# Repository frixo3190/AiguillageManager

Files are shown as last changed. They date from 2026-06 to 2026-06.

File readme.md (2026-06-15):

# 🚂 AiguillageManager — Pilotez en DCC vos aiguillages à solénoïde

<p align="center">
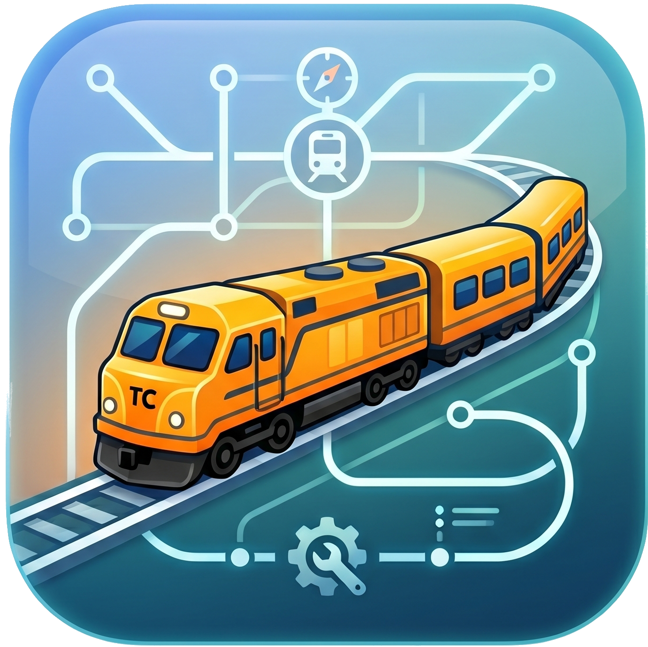
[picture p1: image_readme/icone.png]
AiguillageManager
  
</p>

Le but de ce projet est de numériser et de rendre compatibles DCC les aiguillages à bobines traditionnels (les modèles analogiques classiques que l'on trouve d'occasion pour quelques euros).

<p align="center">
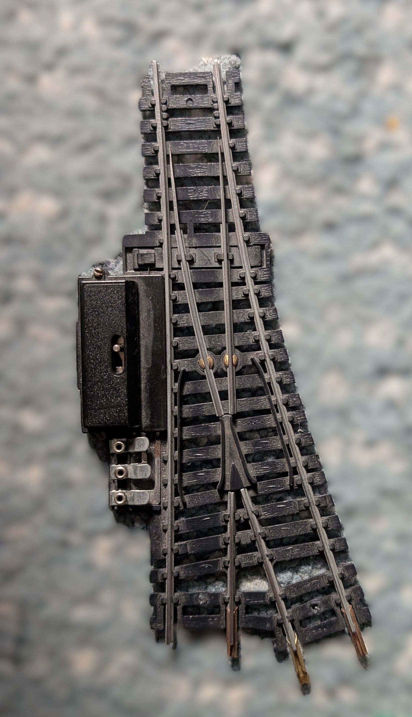
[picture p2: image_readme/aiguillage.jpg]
Aiguillage à bobine traditionnel
  
  <br><em>Aiguillage à bobine standard — le genre d'aiguillage que ce projet permet de piloter en Wi-Fi et en DCC.</em>
</p>

Grâce à ce boîtier, vous pouvez piloter vos aiguillages de deux manières :

- **En Wi-Fi :** Via une ou plusieurs tablettes tactiles synchronisées en temps réel, qui affichent le tracé de votre réseau avec des boutons interactifs.
- **En DCC :** Directement depuis votre télécommande MultiMAUS branchée sur votre centrale ferroviaire.

---

## ✨ Fonctionnalités

### Interface Web (TCO tactile)
- Design glassmorphism, fond de plan personnalisable
- Mode Utilisateur / Mode Configuration
- Drag & drop des switchs, masquage, redimensionnement
- Zoom ×2 à ×10, zoom libre
- Panneau **Historique** des actions
- Panneau **DCC log** : toutes les commandes DCC reçues, avec filtre "aiguillages uniquement"
- **Gyrophare rouge** et sirène 3s quand le signal DCC est perdu
- Badge DCC OK / KO / Arrêt Urgence 🚨
- Bouton **Muette** 🔊/🔇 l'alerte sonore
- Clic sur "DCC OK" → historique DCC ; clic sur 📜 → historique actions

### DCC
- Détection et décodage des adresses d'aiguillage (formule universelle `((addr-33016)/256)*4 + ((addr-33016)%256)/2 + 1`)
- Mapping configurable : chaque switch peut répondre à n'importe quelle adresse DCC (1-99)
- Ordres d'ouverture / fermeture avec sons distincts (notes ascendantes/descendantes)
- Arrêt d'urgence (overlay rouge + badge clignotant + son)
- `logdcc(true/false)` — log brut en console
- `logPin(true/false)` — monitoring de la pin DCC

### WiFi
- Connexion non-bloquante (le serveur démarre sans attendre le WiFi)
- Reconnexion automatique
- LED interne clignote si WiFi perdu
- OTA (mise à jour firmware et filesystem par WiFi)
- Heartbeat toutes les 5s avec timeout 15s (détection de perte de connexion)

### Console navigateur
| Commande | Description |
|---|---|
| `help()` | Affiche l'aide |
| `logdcc(true/false)` | Log DCC brut dans la console |
| `logPin(true/false)` | Active la surveillance pin DCC |
| `cancel_detect_dcc_off(true/false)` | Ignore la perte de signal DCC |

---

## 🛠️ Hardware

Pour matérialiser ce projet, il est nécessaire de fabriquer une carte électronique sur mesure qui sert d'interface de puissance et de sécurité. Vous trouverez dans ce projet un dossier nommé `gerber.zip` contenant tous les fichiers de fabrication industriels.

Pour la commande du PCB, vous pouvez passer par **JLCPCB** (aucun lien ni affiliation). En dehors du délai de livraison proche d'un mois, c'est vraiment le moins cher. Il vous suffit de téléverser le fichier `gerber.zip` sur leur site pour commander et faire imprimer le circuit imprimé professionnel pour moins de 10 €.

Pour les pièces détachées (composants électroniques), je conseille **AliExpress** (aucun lien ni affiliation).

Une fois la carte et les composants reçus, il faudra souder le tout vous-même.

<p align="center">
  Circuit imprimé (PCB)
  <br><em>Carte électronique du projet — interface de puissance et de sécurité pour 6 aiguillages.</em>
</p>

<p align="center">
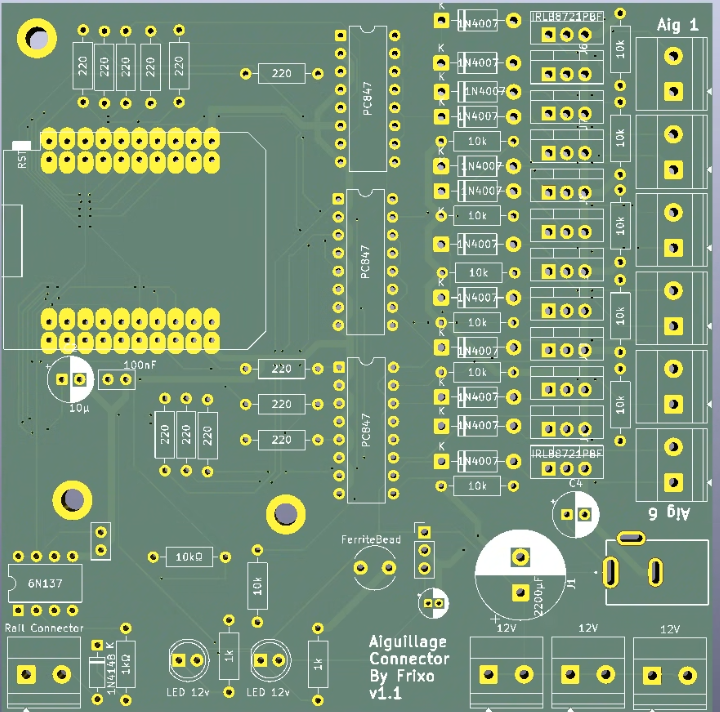
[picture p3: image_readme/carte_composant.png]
PCB avec références des composants
  
  <br><em>PCB avec l'emplacement et les références de chaque composant.</em>
</p>

<p align="center">
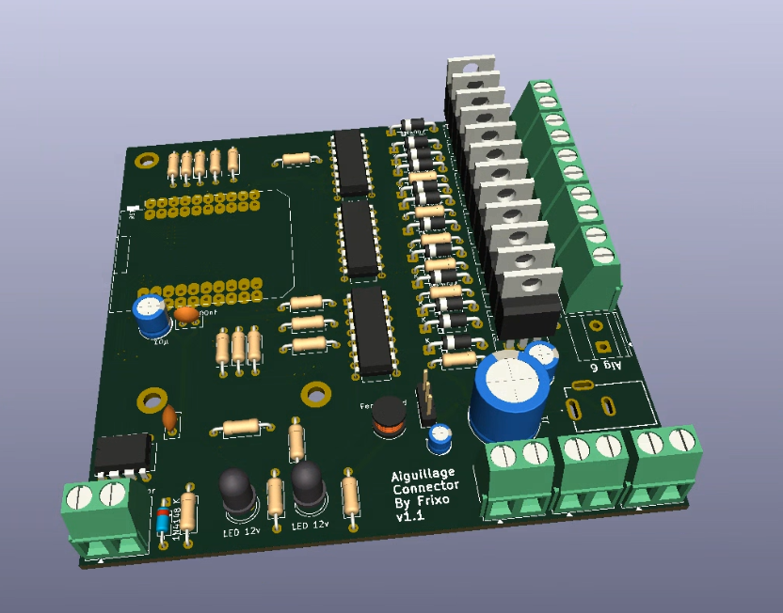
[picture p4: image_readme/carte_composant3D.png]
PCB avec composants 3D
  
  <br><em>PCB avec les composants 3D — vue réaliste de la carte une fois assemblée.</em>
</p>

<p align="center">
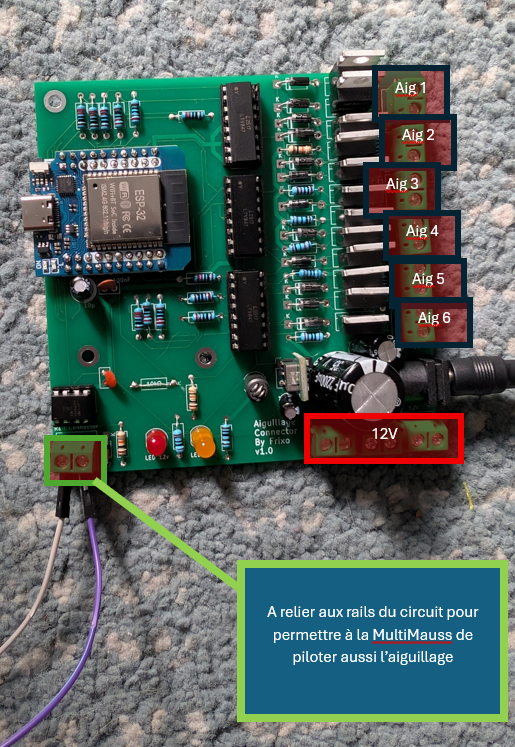
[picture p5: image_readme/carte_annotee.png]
Carte et aiguillage annotés
  
  <br><em>Carte et aiguillage annotés — repérage des principaux composants et connexions.</em>
  <br><em>⚠️ Sur la photo, on voit qu'une résistance de 10 kΩ a été shuntée. Il s'agit d'une erreur de conception de la V1.0, corrigée dans la <strong>V1.1</strong> (présente dans ce projet). Dans la V1.1, cette résistance est correctement soudée sur le circuit imprimé. Dans la V1.0, la résistance est également présente mais a dû être soudée manuellement à l'arrière de la carte de façon peu propre.</em>
</p>

<p align="center">
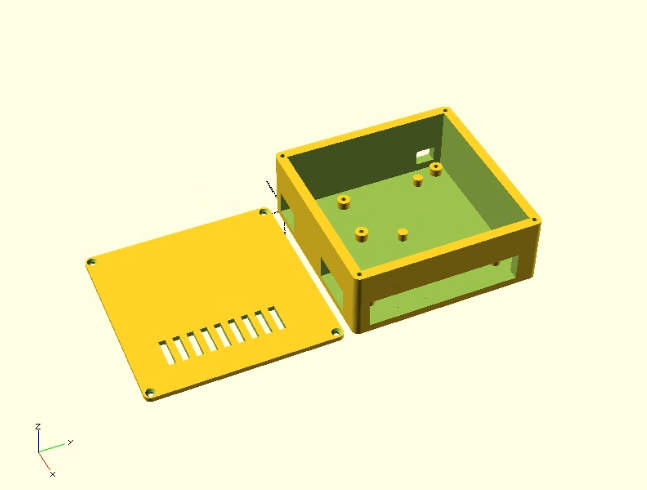
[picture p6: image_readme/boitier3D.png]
Boîtier 3D
  
  <br><em>Boîtier d'impression 3D — pour protéger la carte électronique et la connectique.</em>
</p>

Un fichier **STL** est inclus dans ce projet pour imprimer un boîtier de protection adapté aux dimensions exactes du PCB. Il est recommandé d'imprimer ce boîtier en **PETG** (éviter l'ABS, car la carte peut chauffer un peu). Le fichier STL doit être transformé en GCode comme d'habitude — je conseille le logiciel **CURA** (aucun lien ni affiliation).

En entrée, cette carte doit être alimentée par un **bloc d'alimentation 12V - 2A** (référence exacte : alimentation à découpage 12V 2A avec connecteur Jack DC 5.5 × 2.1 mm). Une fois cette alimentation branchée sur le connecteur Jack de la carte, il n'est plus du tout nécessaire d'alimenter l'ESP32 en USB-C, car le circuit s'occupe de réguler et de distribuer l'énergie nécessaire au microcontrôleur.

En sortie, cette carte électronique fournit de quoi alimenter **jusqu'à 6 aiguillages standards en 12V**, et permet de contrôler individuellement le basculement dans les deux sens (voie directe ou voie déviée) pour chacun de ces 6 aiguillages.

Pour cela, le circuit intègre une **triple sécurité** indispensable :
- L'**optocoupleur rapide 6N137** isole et protège l'ESP32 des tensions élevées et des parasites de la voie DCC.
- Des **optocoupleurs PC817** isolent totalement la partie commande basse tension (3,3V) de la partie puissance (12V) des aiguillages.
- Des **transistors MOSFET** font office d'interrupteurs "gros bras" pour encaisser et envoyer le fort ampérage (plusieurs Ampères) réclamé par les bobines analogiques sans surcharger le microcontrôleur.

### Liste des composants

| Composant | Description / Rôle | Qté |
|---|---|---|
| Module WiFi D1 MINI ESP32 | Microcontrôleur (cerveau du projet, version 30 ou 38 broches selon votre PCB) | 1 |
| Optocoupleur 6N137 | Isolation haute vitesse pour la lecture du signal DCC des rails | 1 |
| Support DIP-8 | Support pour accueillir l'optocoupleur 6N137 sans avoir à le souder directement | 1 |
| Optocoupleurs PC817 | Isolation des signaux de commande des aiguillages (sécurité CPU) | 12 |
| Supports DIP-4 | Supports pour accueillir les 12 optocoupleurs PC817 | 12 |
| Transistors MOSFET | Interrupteurs de puissance pour envoyer les Ampères aux bobines | 12 |
| Diodes 1N4148 | Diode de commutation rapide pour le circuit d'entrée DCC | 1 |
| Diodes 1N4007 | Diodes de roue libre pour protéger le circuit des retours de force des bobines | 12 |
| Résistance 1 kΩ | Protection de la LED interne de l'optocoupleur 6N137 | 1 |
| Résistance 10 kΩ | Résistance de Pull-Up pour la ligne de signal DCC (broche 6) | 1 |
| Résistances (220 Ω à 1 kΩ) | Résistances de commande pour les lignes des transistors | 12 |
| Condensateur 100 nF | Condensateur de découplage pour stabiliser l'alimentation du 6N137 | 1 |
| Borniers à vis 5.08 mm | Connecteurs pour l'arrivée des rails et les sorties vers les aiguillages | Selon design |
| Inducteur de perle de ferrite (6 canaux) | Filtre antiparasite multi-lignes pour bloquer les bruits électromagnétiques | 1 |
| Prise Jack DC femelle | Connecteur d'alimentation pour recevoir le bloc 12V (5.5 × 2.1 mm) | 1 |

> ⚠️ **Conseil important :** Prenez le temps de bien souder chaque composant, dans le bon sens. Un défaut de soudure (point sec, court-circuit, composant inversé) peut rendre la carte inopérante, voire endommager définitivement l'ESP32 ou les composants connectés. Une inspection visuelle à la lampe et un passage au multimètre avant la mise sous tension sont vivement recommandés.

### Détails de conception

- ESP32 Wemos D1 mini32
- Optocoupleur 6N137 pour isolation DCC
- 12 MOSFETs pour piloter 6 aiguillages double-bobine
- Protection anti-surchauffe (impulsions 500ms)
- Synchronisation physique au démarrage (impulsions espacées 600ms)

---

## 🔐 Fichier `secrets.h` (obligatoire)

Avant de compiler, crée le fichier `src/secrets.h` avec tes identifiants WiFi :

```cpp
#ifndef SECRETS_H
#define SECRETS_H

#define WIFI_SSID "ton_ssid"
#define WIFI_PASSWORD "ton_mot_de_passe"

#endif
```

Ce fichier est dans `.gitignore` → pas de risque de l'uploader sur GitHub.

---

## 📦 Upload & Flash

### Première fois (filaire USB)
```bash
pio run -t upload           # Flash firmware
pio run --target uploadfs   # Upload filesystem (HTML/CSS/JS/images)
```

### OTA (mise à jour WiFi)
```bash
pio run -t upload --upload-port AiguillageManager.local
pio run --target uploadfs --upload-port AiguillageManager.local
```

---

## 🔧 Configuration

### Attribution d'adresse DCC
1. Passer en **Mode Configuration**
2. Cliquer droit sur un switch → "Attribuer une adresse d'aiguillage"
3. Saisir un numéro (1-99)
4. Le numéro s'affiche sur le switch

### Plan de fond
1. Mode Configuration → "Plan" → Upload/Photo
2. L'image est redimensionnée à 1920px max et stockée sur l'ESP

---

## 🔄 Historique des versions

- **v1.15+** : Mapping DCC configurable, panneau DCC log, gyrophare, sirène, OTA, heartbeat, badges DCC OK/KO/Urgence

---

## ⚖️ Avertissement légal

Ce projet est fourni à titre éducatif et récréatif. La fabrication, le câblage, la mise sous tension et l'utilisation de cette carte électronique se font **sous votre entière responsabilité**.

Le créateur de ce projet ne peut être tenu responsable :
- d'un défaut de fabrication,
- d'une erreur de conception,
- d'un mauvais branchement,
- d'un court-circuit,
- d'un incendie ou de tout autre dommage matériel ou corporel,
- ni de toute conséquence directe ou indirecte liée à l'utilisation de ce projet.

En réalisant ce projet, vous reconnaissez avoir les compétences nécessaires en soudure et en électronique, ou accepter de vous former avant de commencer.

---

## 🧩 Licence & Crédits

Ce projet est **entièrement libre et open-source**. Vous pouvez l'utiliser, le modifier, le partager et le distribuer sans aucune restriction.

Seule petite attention : si vous le partagez, présentez-le ou en parlez autour de vous, merci de mentionner qu'il a été créé **by Frixo**.

Développé sous supervision humaine, code généré par IA.
Librairies : NmraDcc, ESPAsyncWebServer, ArduinoJson.

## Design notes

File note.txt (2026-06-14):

lancer l'upload littlefs pour les maj web :
pio run --target uploadfs

pio run -t upload --upload-port 192.168.70.43

pio run --target uploadfs --upload-port 192.168.70.43

pio run --target uploadfs --upload-port AiguillageManager.local

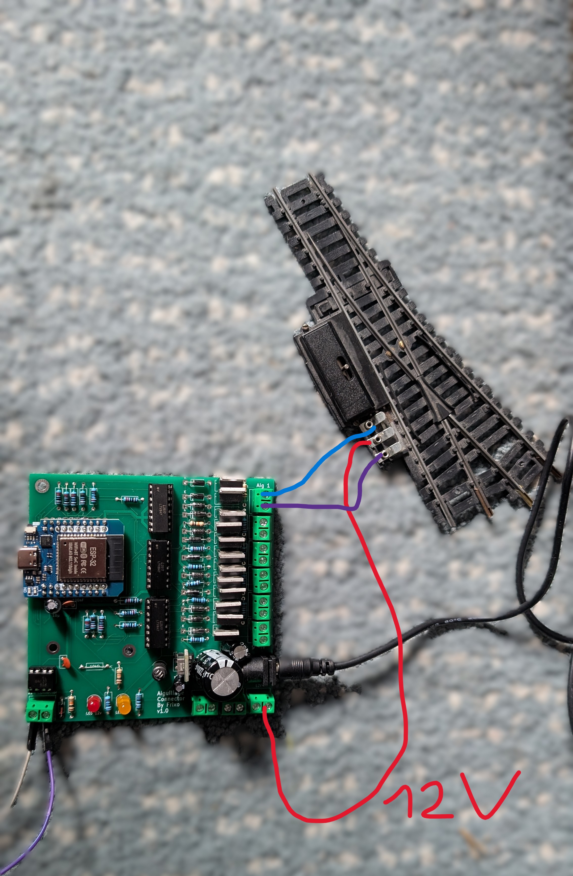
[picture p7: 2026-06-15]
image_readme/non utilisé/carte et aiguillage.jpg

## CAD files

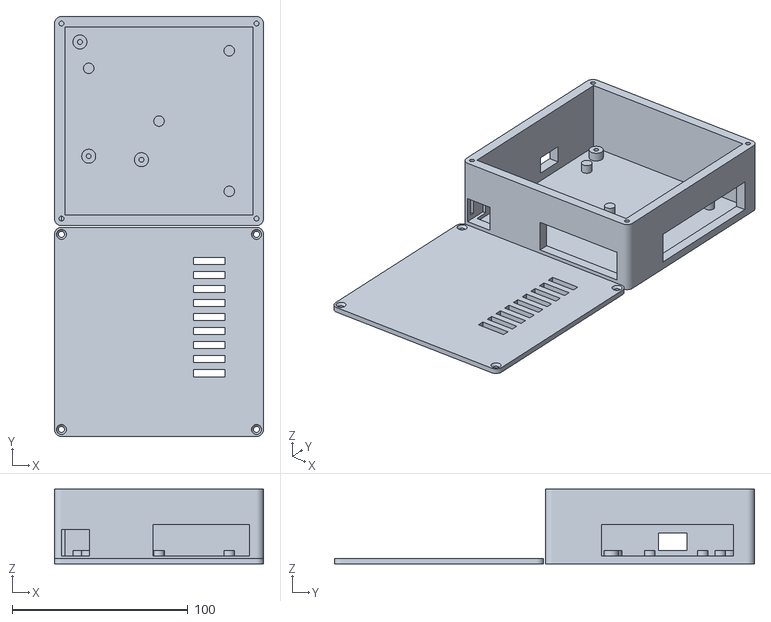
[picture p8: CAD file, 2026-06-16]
boite.stl
119.0 x 239.0 x 42.5

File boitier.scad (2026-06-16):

// --- CONFIGURATION ---
pcb_x = 100; 
pcb_y = 100; 
h_int = 40; 
ep = 2.5; 
marge = 3.5; // Offre 2mm de jeu de chaque côté à l'intérieur
$fn = 64; 

// Positions des 3 trous de vis PCB
trous_pcb = [[5, 95], [10, 30], [40, 28]]; 

// Positions des supports anti-torsion
supports_appui = [[10, 80], [90, 10], [90, 90], [50, 50]];

module base_boitier() {
    difference() {
        // 1. CORPS EXTERNE
        hull() {
            for(x=[0, pcb_x+11], y=[0, pcb_y+11]) 
                translate([x,y,0]) cylinder(h=h_int+ep, r=4);
        }
        
        // 2. VIDAGE INTERNE (Avec le jeu de 2mm de chaque côté)
        translate([2, 2, ep])
            cube([pcb_x+7, pcb_y+7, h_int + 5]);

        // 3. OUVERTURE USB-C (Flanc gauche)
        translate([-5, 60.5, ep+5]) cube([15, 16, 10]); 
        
        // 4. OUVERTURE BORNIERS DROITE (Aiguillages 1 à 6)
        translate([pcb_x+6, 28, ep+2]) cube([10, 75, 18]);
        
        // 5. OUVERTURES BAS
        // Ouverture J2 (DCC Rail) en bas à gauche
        translate([0, -5, ep+2]) cube([16, 15, 15]);
        
        // AJUSTEMENT ICI : Découpe resserrée sur le coin inférieur droit
        // Démarre à X=52 (au lieu de 46) pour éviter le grand vide à gauche du bornier J5
        translate([52, -5, ep+2]) cube([55, 35, 18]);

        // 6. TROUS POUR VIS DU COUVERCLE
        for(x=[0, pcb_x+11], y=[0, pcb_y+11]) {
            translate([x, y, ep + 5]) cylinder(h=h_int, r=1.4);
        }
    }

    // PLOTS DE FIXATION PCB (Centrés)
    for (t = trous_pcb) {
        translate([t[0]+5.5, t[1]+5.5, ep])
            difference() {
                cylinder(h=5, r=4);
                translate([0,0,-1]) cylinder(h=7, r=1.4); 
            }
    }

    // SUPPORTS ANTI-TORSION
    for (s = supports_appui) {
        translate([s[0]+5.5, s[1]+5.5, ep]) cylinder(h=5, r=3);
    }
}

module couvercle() {
    translate([0, -120, 0]) 
    difference() {
        // Plaque du couvercle
        hull() {
            for(x=[0, pcb_x+11], y=[0, pcb_y+11]) 
                translate([x,y,0]) cylinder(h=3, r=4);
        }
        
        // TROUS DE PASSAGE VIS M3 (fraisés)
        for(x=[0, pcb_x+11], y=[0, pcb_y+11]) {
            translate([x,y,-1]) cylinder(h=5, r=1.7); 
            translate([x,y,1.5]) cylinder(h=2, r1=1.7, r2=3.2); 
        }
            
        // FENTES D'AÉRATION (Zone MOSFETs)
        for(i=[0:8]) translate([75, 30 + i*8, -1]) cube([18, 4, 5]);
    }
}

// Appel des modules
base_boitier();
couvercle();

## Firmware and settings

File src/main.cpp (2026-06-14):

#include <Arduino.h>
#include <WiFi.h>
#include <ESPAsyncWebServer.h>
#include <LittleFS.h>
#include <ArduinoJson.h>
#include <ESPmDNS.h>
#include <NmraDcc.h>
#include <ArduinoOTA.h>
#include "secrets.h"

const char* ssid = WIFI_SSID;
const char* password = WIFI_PASSWORD;

AsyncWebServer server(80);

NmraDcc Dcc;

#define DCC_PIN 16
#define DCC_SIGNAL_TIMEOUT 500

unsigned long pinTimers[40] = {0};
int switchStates[6] = {0};
int switchDccAddresses[6] = {1, 2, 3, 4, 5, 6};
AsyncEventSource * events;
unsigned long lastDccSignal = 0;
bool signalPresent = true;
int dccPinLastState = -1;
unsigned long lastDccPinEvent = 0;
bool dccPinLogEnabled = false;
bool emergencyStopActive = false;
unsigned long emergencyStartTime = 0;
uint16_t lastUnknownAddr = 0;
uint8_t lastUnknownCmd = 0;
unsigned long lastUnknownTime = 0;

const int pinsAiguillages[6][2] = {
  {26, 17}, 
  {18, 19}, 
  {21, 22}, 
  {23, 25}, 
  {27, 32}, 
  {33, 14}  
};

void loadDccAddresses() {
  File configFile = LittleFS.open("/config.json", "r");
  if (configFile) {
    StaticJsonDocument<2048> doc;
    DeserializationError error = deserializeJson(doc, configFile);
    if (!error) {
      JsonArray switches = doc["switches"];
      int i = 0;
      for (JsonObject sw : switches) {
        if (i >= 6) break;
        switchDccAddresses[i] = sw["dccAddress"] | (i + 1);
        i++;
      }
      for (; i < 6; i++) {
        switchDccAddresses[i] = i + 1;
      }
    }
    configFile.close();
  }
}

void notifyDccMsg(DCC_MSG * msg) {
  lastDccSignal = millis();
  if (emergencyStopActive && emergencyStartTime > 0 && (millis() - emergencyStartTime > 2000)) {
    emergencyStopActive = false;
  }
  if (!signalPresent) {
    signalPresent = true;
    events->send("{\"present\":true}", "dcc-signal");
  }
  
  if (msg->Size >= 3) {
    uint16_t addr = (msg->Data[0] << 8) | msg->Data[1];
    uint8_t cmd = msg->Data[2];
    
    int base = addr - 33016;
    int calcSwitch = (base / 256) * 4 + ((base % 256) / 2) + 1;
    int mode = (addr % 2) + 1;
    
    int switchId = -1;
    for (int i = 0; i < 6; i++) {
      if (switchDccAddresses[i] == calcSwitch) {
        switchId = i;
        break;
      }
    }
    if (switchId < 0 && calcSwitch >= 1 && calcSwitch <= 6) {
      switchId = calcSwitch - 1;
    }
    
    if (switchId >= 0) {
      int pinIndex = mode - 1;
      int pinToPulse = pinsAiguillages[switchId][pinIndex];
      
      Serial.println("DCC: Aiguillage " + String(calcSwitch) + " mode " + String(mode));
      
      switchStates[switchId] = mode - 1;
      
      digitalWrite(pinToPulse, HIGH);
      pinTimers[pinToPulse] = millis();
      if (pinTimers[pinToPulse] == 0) pinTimers[pinToPulse] = 1;
      
      char jsonBuf[200];
      snprintf(jsonBuf, sizeof(jsonBuf), "{\"id\":%d,\"state\":%d,\"source\":\"dcc\",\"address\":%d,\"cmd\":%d}", switchId, switchStates[switchId], addr, cmd);
      events->send(jsonBuf, "dcc-switch");
    } else {
      if (addr == lastUnknownAddr && cmd == lastUnknownCmd && millis() - lastUnknownTime < 1000) {
        // already reported, skip
      } else {
        lastUnknownAddr = addr;
        lastUnknownCmd = cmd;
        lastUnknownTime = millis();
        Serial.printf("DCC: Adresse inconnue %d\n", addr);
        char jsonBuf[100];
        snprintf(jsonBuf, sizeof(jsonBuf), "{\"address\":%d,\"cmd\":%d}", addr, cmd);
        events->send(jsonBuf, "dcc-unknown");
      }
    }
  }
}

void notifyDccSpeed(uint16_t addr, DCC_ADDR_TYPE addrType, uint8_t speed, DCC_DIRECTION dir, DCC_SPEED_STEPS speedSteps) {
  lastDccSignal = millis();
  if (!signalPresent) {
    signalPresent = true;
    events->send("{\"present\":true}", "dcc-signal");
  }
  
  if (speed == 1) {
    emergencyStopActive = true;
    emergencyStartTime = millis();
    Serial.println("DCC: ARRET D'URGENCE - Loc " + String(addr));
    events->send("{\"active\":true}", "emergency-stop");
    events->send("{\"active\":1}", "dcc-emergency");
  } else {
    emergencyStopActive = false;
  }
}

void notifyDccNormalOperation(uint16_t addr, DCC_ADDR_TYPE addrType) {
  lastDccSignal = millis();
  emergencyStopActive = false;
  events->send("{\"active\":false}", "emergency-stop");
}

void notifyDccSubsystemStop(uint8_t StopState) {
  lastDccSignal = millis();
  emergencyStopActive = (StopState == 1);
  if (emergencyStopActive) emergencyStartTime = millis();
  Serial.print("DCC: SUBSYSTEM STOP - ");
  Serial.println(StopState);
  char jsonBuf[100];
  snprintf(jsonBuf, sizeof(jsonBuf), "{\"active\":%d}", StopState == 1 ? 1 : 0);
  events->send(jsonBuf, "emergency-stop");
  if (emergencyStopActive) {
    events->send(jsonBuf, "dcc-emergency");
  }
}

void setup() {
  Serial.begin(115200);

  for(int i = 0; i < 6; i++) {
    pinMode(pinsAiguillages[i][0], OUTPUT);
    digitalWrite(pinsAiguillages[i][0], LOW);
    
    pinMode(pinsAiguillages[i][1], OUTPUT);
    digitalWrite(pinsAiguillages[i][1], LOW);
  }

  if (!LittleFS.begin(true)) {
    Serial.println("Erreur LittleFS");
    return;
  }

  // --- NOUVEAU : Synchronisation physique au démarrage ---
  Serial.println("Initialisation physique des aiguillages...");
  File configFile = LittleFS.open("/config.json", "r");
  if (configFile) {
    StaticJsonDocument<2048> doc; 
    DeserializationError error = deserializeJson(doc, configFile);
    
    if (!error) {
      JsonArray switches = doc["switches"];
      int id = 0;
      for (JsonObject sw : switches) {
        if (id >= 6) break;
        
        int state = sw["state"]; // 0 (Mode 1) ou 1 (Mode 2)
        int pinToPulse = pinsAiguillages[id][state];
        
        Serial.println("Synchro au demarrage - Aiguillage " + String(id + 1) + " : pin " + String(pinToPulse));
        
        digitalWrite(pinToPulse, HIGH);
        delay(500); // Impulsion de 500ms
        digitalWrite(pinToPulse, LOW);
        
        delay(600); // Attente de 600ms pour soulager l'alimentation
        id++;
      }
    }
    configFile.close();
    Serial.println("Synchronisation terminee.");
  } else {
    Serial.println("Aucun fichier config.json, passage avec les valeurs par defaut.");
  }
  // -------------------------------------------------------
  
  loadDccAddresses();

  pinMode(DCC_PIN, INPUT);
  pinMode(LED_BUILTIN, OUTPUT);
  digitalWrite(LED_BUILTIN, HIGH); // éteinte au départ
  Dcc.pin(DCC_PIN, 0);
  Dcc.init(MAN_ID_DIY, 10, FLAGS_DCC_ACCESSORY_DECODER, 0);

  lastDccSignal = millis();

  events = new AsyncEventSource("/events");
  events->onConnect([](AsyncEventSourceClient * client) {
    client->send("connected", NULL, millis(), 1000);
  });
  server.addHandler(events);

  DefaultHeaders::Instance().addHeader("Cache-Control", "no-cache, no-store, must-revalidate");

  WiFi.setHostname("AiguillageManager");
  WiFi.begin(ssid, password);
  Serial.print("Connexion WiFi a ");
  Serial.println(ssid);
  Serial.println("(non-bloquant, le serveur demarre sans attendre le WiFi)");

  ArduinoOTA.setHostname("AiguillageManager");
  ArduinoOTA.onStart([]() { Serial.println("OTA: mise a jour..."); });
  ArduinoOTA.onEnd([]() { Serial.println("OTA: termine"); });
  ArduinoOTA.onProgress([](unsigned int progress, unsigned int total) {
    Serial.printf("OTA: %u%%\r", (progress * 100) / total);
  });
  ArduinoOTA.onError([](ota_error_t error) {
    Serial.printf("OTA: erreur %u\n", error);
  });
  ArduinoOTA.begin();

  server.on("/switch", HTTP_GET, [](AsyncWebServerRequest *request){
    if(request->hasParam("id") && request->hasParam("mode")){
      int id = request->getParam("id")->value().toInt();
      int mode = request->getParam("mode")->value().toInt();
      
      Serial.println("aiguillage " + String(id) + " : mode " + String(mode)); 

      if (id >= 1 && id <= 6 && (mode == 1 || mode == 2)) {
        int pinIndex = mode - 1; 
        int pinToPulse = pinsAiguillages[id - 1][pinIndex]; 
        
        digitalWrite(pinToPulse, HIGH); 
        
        pinTimers[pinToPulse] = millis(); 
        if(pinTimers[pinToPulse] == 0) pinTimers[pinToPulse] = 1;

        switchStates[id - 1] = mode - 1;

        String user = request->hasParam("user") ? request->getParam("user")->value() : "";
        char jsonBuf[200];
        snprintf(jsonBuf, sizeof(jsonBuf), "{\"id\":%d,\"state\":%d,\"source\":\"web\",\"user\":\"%s\"}", id - 1, mode - 1, user.c_str());
        events->send(jsonBuf, "dcc-switch");
      }
    }
    request->send(200, "text/plain", "OK");
  });

  server.on("/save", HTTP_POST, [](AsyncWebServerRequest *request){}, NULL, 
    [](AsyncWebServerRequest *request, uint8_t *data, size_t len, size_t index, size_t total) {
      File file = LittleFS.open("/config.json", "w");
      if (file) {
        file.write(data, len);
        file.close();
        loadDccAddresses();
        String saveId = request->hasParam("_save") ? request->getParam("_save")->value() : "";
        String saveUser = request->hasParam("_user") ? request->getParam("_user")->value() : "";
        String sseMsg = "{\"_save\":\"" + saveId + "\",\"_user\":\"" + saveUser + "\"}";
        events->send(sseMsg.c_str(), "config-update");
        request->send(200, "text/plain", "OK");
      } else {
        request->send(500, "text/plain", "Erreur");
      }
  });

  server.on("/upload", HTTP_POST, [](AsyncWebServerRequest *request){},
    [](AsyncWebServerRequest *request, String filename, size_t index, uint8_t *data, size_t len, bool final) {
      static File uploadFile;
      if (!index) {
        uploadFile = LittleFS.open("/fond.jpg", "w");
        if (!uploadFile) {
          Serial.println("Upload: ECHEC ouverture fichier");
        } else {
          Serial.println("Upload: ouverture fichier OK");
        }
      }
      if (uploadFile) {
        uploadFile.write(data, len);
      }
      if (final) {
        if (uploadFile) {
          uploadFile.close();
          Serial.println("Upload: termine OK");
          request->send(200, "text/plain", "OK");
        } else {
          request->send(500, "text/plain", "Erreur ecriture fichier");
        }
      }
  });
  
  server.on("/config.json", HTTP_GET, [](AsyncWebServerRequest *request){
    if (LittleFS.exists("/config.json")) {
      AsyncWebServerResponse *response = request->beginResponse(LittleFS, "/config.json", "application/json");
      response->addHeader("Cache-Control", "no-cache, no-store, must-revalidate");
      request->send(response);
    } else {
      request->send(404, "text/plain", "Not found");
    }
  });

  server.on("/fond.jpg", HTTP_GET, [](AsyncWebServerRequest *request){
    if (!LittleFS.exists("/fond.jpg")) {
      request->send(404, "text/plain", "Not found");
      return;
    }
    AsyncWebServerResponse *response = request->beginResponse(LittleFS, "/fond.jpg", "image/jpeg");
    request->send(response);
  });

  server.on("/icone.png", HTTP_GET, [](AsyncWebServerRequest *request){
    if (LittleFS.exists("/icone.png")) {
      AsyncWebServerResponse *response = request->beginResponse(LittleFS, "/icone.png", "image/png");
      response->addHeader("Cache-Control", "no-cache, no-store, must-revalidate");
      request->send(response);
    } else {
      request->send(404, "text/plain", "Not found");
    }
  });

  server.on("/manifest.json", HTTP_GET, [](AsyncWebServerRequest *request){
    if (LittleFS.exists("/manifest.json")) {
      AsyncWebServerResponse *response = request->beginResponse(LittleFS, "/manifest.json", "application/json");
      response->addHeader("Cache-Control", "no-cache, no-store, must-revalidate");
      response->addHeader("Pragma", "no-cache");
      response->addHeader("Expires", "0");
      request->send(response);
    } else {
      request->send(404, "text/plain", "Not found");
    }
  });

  server.on("/delete-plan", HTTP_GET, [](AsyncWebServerRequest *request){
    if (LittleFS.exists("/fond.jpg")) {
      LittleFS.remove("/fond.jpg");
      Serial.println("Plan de fond supprimé");
    }
    request->send(200, "text/plain", "OK");
  });

  server.on("/dccpinlog", HTTP_GET, [](AsyncWebServerRequest *request){
    if (request->hasParam("on")) {
      dccPinLogEnabled = request->getParam("on")->value() == "1";
      if (dccPinLogEnabled) events->send("{\"test\":true}", "dcc-pin");
      request->send(200, "text/plain", "OK");
    } else {
      request->send(400, "text/plain", "Missing param");
    }
  });

  server.serveStatic("/", LittleFS, "/").setDefaultFile("index.html").setCacheControl("no-store");

  server.begin();
}

unsigned long lastWifiCheck = 0;
unsigned long lastHeartbeat = 0;
bool wifiWasConnected = false;

void loop() {
  ArduinoOTA.handle();

  unsigned long now = millis();
  if (now - lastHeartbeat >= 5000) {
    lastHeartbeat = now;
    events->send("{\"heartbeat\":true}", "dcc-ping");
  }
  Dcc.process();
  if (now - lastWifiCheck >= 3000) {
    lastWifiCheck = now;
    int s = WiFi.status();
    if (s == WL_CONNECTED) {
      if (!wifiWasConnected) {
        wifiWasConnected = true;
        Serial.print("WiFi connecte ! IP: ");
        Serial.println(WiFi.localIP().toString());
        MDNS.begin("AiguillageManager");
      }
    } else {
      if (wifiWasConnected) {
        wifiWasConnected = false;
        Serial.println("WiFi perdu, reconnexion...");
      }
      if (s == WL_DISCONNECTED || s == WL_CONNECTION_LOST || s == WL_CONNECT_FAILED) {
        WiFi.disconnect();
        delay(100);
        WiFi.begin(ssid, password);
      }
    }
  }

  if (WiFi.status() == WL_CONNECTED) {
    digitalWrite(LED_BUILTIN, HIGH);
  } else {
    if ((now / 500) % 2 == 0) {
      digitalWrite(LED_BUILTIN, LOW);
    } else {
      digitalWrite(LED_BUILTIN, HIGH);
    }
  }

  int cur = digitalRead(DCC_PIN);
  if (cur != dccPinLastState && (now - lastDccPinEvent >= 50)) {
    dccPinLastState = cur;
    lastDccPinEvent = now;
    if (dccPinLogEnabled) {
      char buf[50];
      snprintf(buf, sizeof(buf), "{\"pin\":%d,\"state\":%d}", DCC_PIN, cur);
      events->send(buf, "dcc-pin");
    }
  }
  
  if (emergencyStopActive && emergencyStartTime > 0 && (millis() - emergencyStartTime >= 10000)) {
    emergencyStopActive = false;
  }
  
  if (signalPresent && !emergencyStopActive && (millis() - lastDccSignal >= DCC_SIGNAL_TIMEOUT)) {
    signalPresent = false;
    events->send("{\"present\":false}", "dcc-signal");
  }
  
  for (int i = 0; i < 40; i++) {
    if (pinTimers[i] > 0 && (millis() - pinTimers[i] >= 500)) {
      digitalWrite(i, LOW); 
      pinTimers[i] = 0;     
    }
  }
}
